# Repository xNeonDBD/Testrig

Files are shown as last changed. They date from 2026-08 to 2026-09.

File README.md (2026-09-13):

# Line Following Robot

A compact line-following robot designed around an ESP32, N20 geared motors with encoders, and a straight analog IR sensor array.

The chassis went through **three main design stages** — V1, V2, and V2 Final — before settling on a simpler, more practical, and more printable layout. This README documents each stage in order, including what changed and why.

---

## Components

### Electronic

- **Microcontroller:** ESP32
  - Specific version: __________
- **IR Sensor Array:** Analog straight IR sensor array
- **Motor Driver:** TB6612FNG
- **Battery:** 2 × 2.7 V Li-ion batteries
- **Battery Holder:** 1
- **Power Converter / Buck Converter:** __________

### Mechanical

- **Motors:** 2 × N20 6 V geared motors with encoders
- **Wheels:** 2 × high-traction 32 mm wheels
- **Caster Wheel:** 1 × caster ball mount
- **Chassis:** Custom CAD-designed chassis
- **Fasteners:** M2.0 nuts and screws

---

## Chassis Design History

### V1 — Curved IR Array Design (Dropped Early)

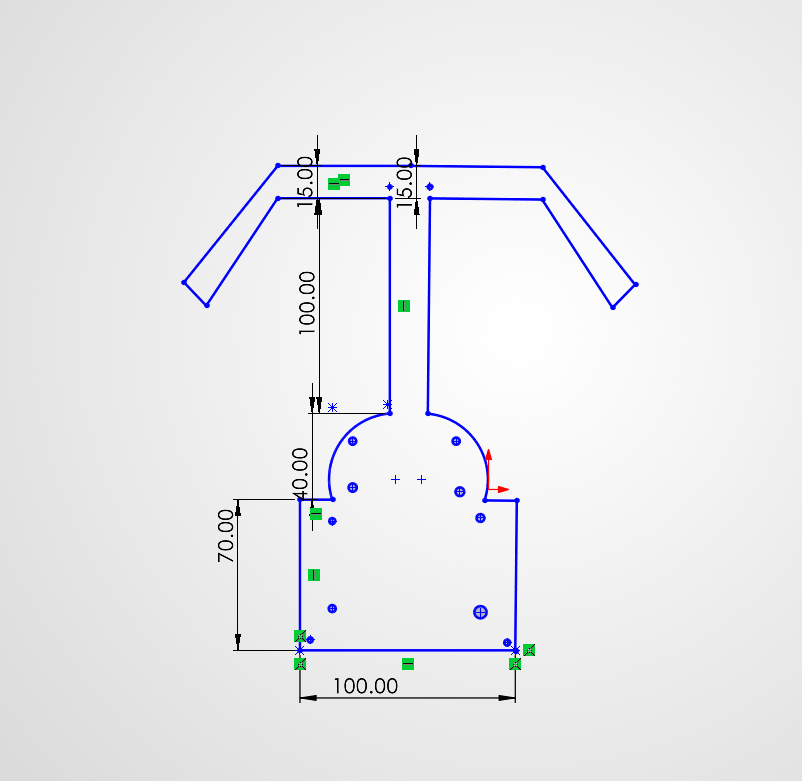
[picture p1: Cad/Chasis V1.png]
Chassis V1


The first version was designed around a **curved IR sensor array**. The idea was to place the sensors along a curved front section so the array could cover a wider area while following the line. The chassis also had to accommodate the required sensor mounting holes and spacing.

This version was **abandoned very quickly**, before it went far into detailed CAD, once two major problems became clear:

1. **Coding complexity** — A curved sensor arrangement requires more complicated sensor mapping and calibration. Since the sensor positions aren't evenly aligned along a straight line, converting the readings into a reliable position/error value is more difficult.
2. **CAD hole spacing** — Getting the correct hole positions, lengths, and widths for the curved arrangement became a problem almost immediately during modelling. Small changes in sensor dimensions or mounting positions affected the rest of the chassis.

Rather than pushing through these issues, the curved-array design was dropped early in favour of a simpler straight sensor arrangement, which became V2.

---

### V2 — Straight Array with Diagonal Slots

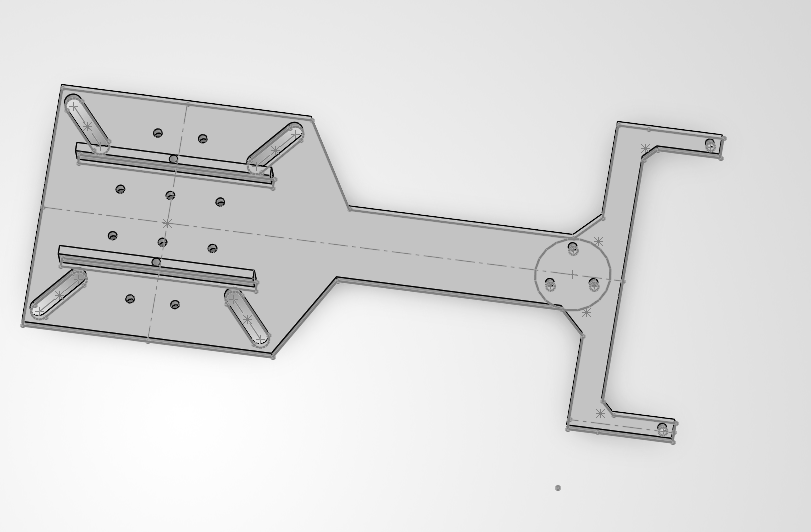
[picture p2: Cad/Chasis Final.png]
Chassis V2


V2 replaced the curved array with a **straight analog IR sensor array**, since sensors on a single straight line are far easier to read, calibrate, and map to a position/error value.

**Key changes from V1:**

- Replaced the curved IR array with a straight analog IR array.
- Added a **long straight mounting slot** for the IR sensor/PCB, so sensor position could be adjusted instead of fixed.
- Improved the PCB mounting arrangement.
- Added two large rectangular recessed/extruded sections for the battery holder, so it sits securely instead of shifting during operation.
- Battery holder/PCB could be secured further with mounting screws if needed.

**Why diagonal slots were used for mounting holes:**

At this stage, most of the mounting holes (not just the IR sensor mount) were also cut as **diagonal/angled slots** rather than fixed circular holes. The reasoning at the time was to build in extra tolerance — since the chassis depends on several separate components (motors, PCB, battery holder) lining up together, slots gave room to shift each part slightly during assembly to compensate for small CAD or print inaccuracies, without needing to redesign or reprint the chassis. It felt like a safer, more forgiving choice while the exact component dimensions were still being finalised.

This made V2 more flexible during initial assembly, but it introduced a new problem that only became clear once parts were actually mounted and tested — covered in V2 Final below.

---

### V2 Final — Fixed Holes + Reduced Width

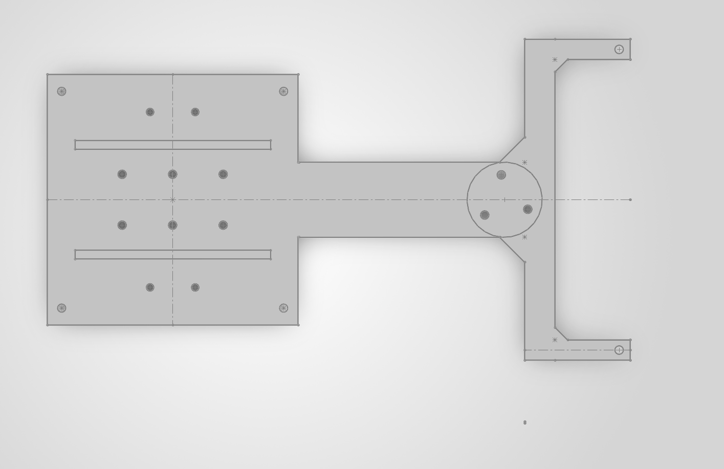
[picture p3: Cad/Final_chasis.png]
Chassis Final


V2 Final keeps the straight IR array and general layout from V2, but corrects two problems discovered after building and testing V2: loose mounting and a chassis that didn't fit the printer.

**Change 1 — All slots removed, replaced with fixed holes:**

Every slot used for mounting in V2 — including the IR sensor mounting slot — was **removed and replaced with fixed-position circular holes** at defined spacing. The chassis no longer has any adjustable mountings.

The extra tolerance from slots turned out to cause more problems than it solved: mounting screws sat loose inside the slots instead of clamping tightly, letting the PCB, sensor array, and brackets shift slightly under vibration or load from the motors. Fixed holes with accurate, pre-calculated spacing removed that play entirely, giving a tighter, more repeatable, more rigid assembly across every mounting point on the chassis.

**Change 2 — Overall chassis width reduced:**

The original V2 chassis was too **long to fit flat on the 3D printer's build plate**. The only way to print it at that size would have been to stand it up at an angle and rely on support structures, which was rejected for three reasons:

1. **Resource waste** — angled printing with supports uses a large amount of extra filament that just gets discarded afterward.
2. **Holes get blocked by supports** — mounting and sensor holes risked being filled in or distorted by support material generated underneath them, requiring cleanup and risking inaccurate final dimensions.
3. **Excessive print time** — for a relatively simple, flat chassis part, printing vertically with supports takes far longer than justified.

To avoid all three issues at once, the chassis **width was reduced** so the entire part fits flat on the print bed in a single orientation, with no supports required.

**Net result:** V2 Final is fully rigid (no loose slots anywhere), lighter, simpler to assemble, and cheaper/faster to print (flat, no supports) than V2 — without losing any of the functional improvements V2 made over V1.

---

## Chassis Design Features

### Lightweight, Simple Chassis

V2 Final favours a **lightweight and simple structure** over the more complex, feature-heavy layout of earlier revisions. With slots removed in favour of fixed holes and the width trimmed down to fit the print bed, the chassis uses less material, prints faster, and has fewer geometric features that could go wrong during modelling or printing. The design prioritises a clean, repeatable, no-frills structure that's easy to assemble and easy to reprint if needed.

```text
        IR SENSOR ARRAY
    ─────────────────────
              ↑
          Fixed hole
    ─────────────────────

             CHASSIS
```

### Fixed Mounting Holes (V2 Final)

All mounting holes on the chassis — including the IR sensor mount, PCB/electronics mounting, and the motor-side mounting pattern — use **fixed circular holes** at defined spacing, visible in `Final_chasis.png`. There are no adjustable/slotted mountings left on the current chassis.

Fixed holes were chosen over slots because:

- Slots allowed the mounting screws to sit loose rather than clamping tightly.
- Loose screws risk shifting the PCB, sensor, or bracket position over time, especially with vibration from the motors.
- Fixed holes with accurate spacing give a more rigid, repeatable assembly once tightened.

### Reduced Chassis Width (V2 Final)

The V2 chassis length exceeded the 3D printer's flat build area. Printing it as-is would have required standing the part up at an angle with support structures, which was rejected for three reasons:

- **Wasted material** — supports consume significant extra filament for no functional benefit.
- **Blocked holes** — mounting and sensor holes could get filled or distorted by support material underneath them.
- **Long print time** — a simple flat chassis shouldn't need a lengthy angled/supported print.

The chassis width was reduced in V2 Final so the whole part prints flat on the bed in one orientation, with no supports needed.

### Battery Mount

Two large rectangular sections provide a stable location for the battery holder. It can be placed on top of the base and secured with mounting screws if required, preventing the batteries from shifting during sharp turns.

### Caster Ball Mount

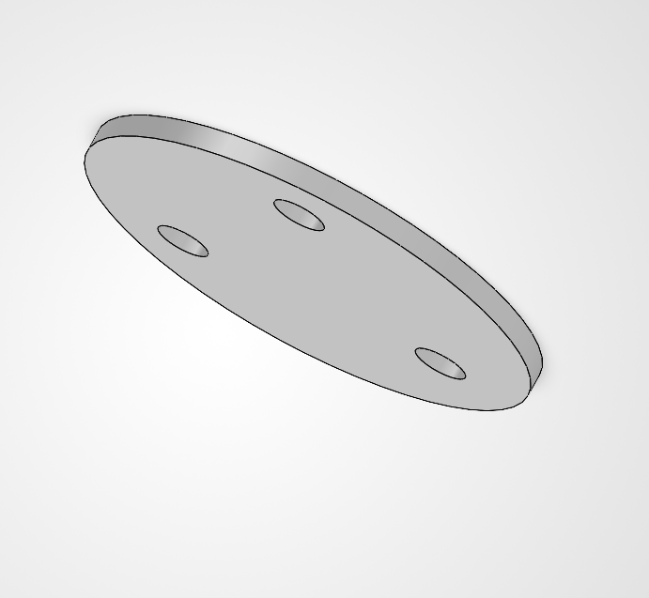
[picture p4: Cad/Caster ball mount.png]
Caster Ball Mount


The caster ball mount (`Caster_Ball_Mount.SLDPRT`) is currently a **working/scratch file**, kept separate from the main chassis so it can be freely edited and iterated on.

It's being used to test and lock down:

- Motor mounting hole positions and spacing for the 2 N20 motors
- Final caster ball mounting height and hole dimensions relative to the wheels

Once the correct dimensions are confirmed through physical testing, the finalised values will be transferred into the main chassis file (`Chasis_final.SLDPRT`).

### Bracket

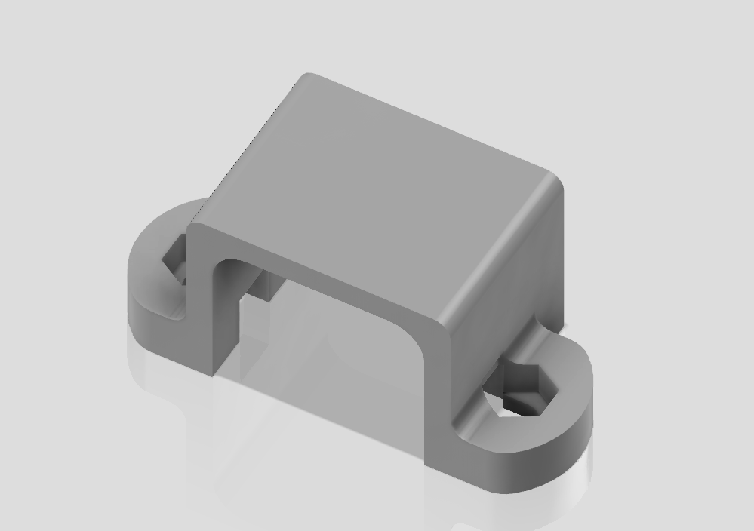
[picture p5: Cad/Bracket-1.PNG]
Bracket


A supporting bracket part (`Bracket.SLDPRT`) used alongside the chassis assembly.

---

## CAD Design

The chassis was designed with emphasis on:

- Simple manufacturability
- Lightweight, low-material structure
- Easy PCB mounting
- Secure battery placement
- Easy access to electronics
- Compatibility with N20 motors and 32 mm wheels
- Fitting flat on the 3D printer bed without supports

Final chassis dimensions and hole positions may still be adjusted after physical testing, since actual component tolerances can differ from CAD dimensions.

### CAD Change Log (Chronological)

| Stage | Change | Reason |
|---|---|---|
| V1 → V2 | Curved IR array replaced with straight IR array | Curved layout caused sensor-mapping/coding complexity and CAD hole-spacing problems |
| V2 | Diagonal/angled slots used for general mounting holes | Intended to give tolerance for component/print inaccuracies during assembly |
| V2 → V2 Final | All slots removed, including the IR sensor slot, replaced with fixed circular holes at defined spacing | Slots left mounting screws too loose, allowing parts to shift under vibration or load; chassis no longer needs adjustable mounts |
| V2 → V2 Final | Overall chassis width reduced | Original V2 length didn't fit flat on the print bed; avoids wasteful angled/supported prints |

---

## Assembly

1. Mount the two N20 motors to the chassis.
2. Install the 32 mm wheels on the motor shafts.
3. Install the caster ball mount.
4. Mount the ESP32 and motor driver.
5. Install the analog IR sensor array.
6. Place the two Li-ion batteries in the battery holder.
7. Secure the battery holder using the provided mounting arrangement.
8. Connect the motors, encoder outputs, IR array, ESP32, motor driver, and power system.
9. Confirm all fixed mounting holes are properly tightened.

---

## Design Considerations

One of the main problems throughout the CAD stage was **hole placement and dimensional accuracy**. Since the chassis depends on several different components being mounted together, even a small error in hole spacing or width can cause problems during physical assembly.

V1 was dropped almost immediately because a curved sensor layout compounded both coding complexity and CAD hole-spacing issues, so effort was redirected into a straight-array design (V2) very early.

V2 initially used diagonal slots liberally across the mounting holes, treating adjustability as a safety margin against CAD or print inaccuracy. In practice, this backfired — slots meant to smooth over minor errors and screws sat loose instead of clamping, letting parts shift under vibration. V2 Final corrected this by converting every mounting hole, including the IR sensor mount, to fixed positions with accurate spacing. The chassis is now built entirely around fixed, rigid mounting rather than adjustability.

Manufacturability on the actual printer also forced a change in V2 Final. The original V2 length couldn't fit flat within the print bed, and printing it angled with supports would have wasted filament, risked blocking holes with support material, and taken far longer than justified for a simple flat part. Reducing the chassis width solved all three problems at once by keeping the whole print flat and support-free, while also keeping the design lightweight and simple.

---

## Testing Checklist

- Motor mounting hole alignment
- Wheel clearance
- Caster height
- IR sensor height from the track
- IR sensor position relative to the wheels
- Battery holder fit
- PCB mounting holes
- Screw clearance
- Cable routing
- Overall chassis balance
- Fixed mounting holes are tight with no play (post slot-removal)
- Chassis prints flat on the bed without supports

---

## Future Improvements

- Finalising the exact ESP32 variant
- Improving PCB mounting
- Final circuit design
- Maze solving algorithm
- Adding IMU for perfect turning
- Testing different types of IR sensors (digital vs analog)
- Optimising the chassis after the first physical prototype

---

## Repository Structure

```text
.
├── Cad/
│   ├── Bracket-1.PNG
│   ├── Bracket.SLDPRT
│   ├── Caster ball mount.png
│   ├── Caster_Ball_Mount.SLDPRT
│   ├── Chasis Final.png
│   ├── Chasis V1.png
│   ├── Chasis.SLDPRT
│   ├── Chasis_final.SLDPRT
│   └── Final_chasis.png
├── Docs/
│   └── Components/
├── Firmware/
├── BUILDLOG.md
└── README.md
```

---

## Current Status

| Part | Status |
|---|---|
| N20 6 V Motors | Selected |
| ESP32 | Selected — version TBD |
| Motor Driver | TB6612FNG |
| IR Sensor | Straight analog array |
| Battery | 2 × Li-ion |
| Battery Holder | Selected |
| Wheels | Selected |
| Chassis V1 | Dropped early (curved array issues) |
| Chassis V2 | Superseded (diagonal slots caused loose mounting) |
| Chassis V2 Final | Current design (`Chasis_final.SLDPRT` / `Final_chasis.png`) |
| PCB Mounting | Fixed holes (all slots removed in V2 Final) |
| Chassis Width | Reduced in V2 Final to fit print bed flat |
| IR Sensor Mount | Fixed hole (no longer adjustable) |
| Battery Mount | Added |
| Caster Ball Mount | In progress — scratch file for dimension testing |

---

## Notes

This chassis is still a prototype. Final dimensions may change after testing the actual motors, wheels, sensor array, battery holder, and electronics together.

**V1** was only a brief exploration — dropped very quickly once the curved sensor array introduced compounding coding and CAD problems.

**V2** introduced the straight sensor array and used slots across most mounting points to allow for assembly tolerance — a choice that later proved to make the assembly too loose.

**V2 Final** fixed both remaining issues from V2: every mounting hole, including the IR sensor mount, was converted to a fixed, precisely spaced hole for rigidity, and the chassis width was reduced so the part prints flat on the bed without wasteful, hole-blocking, time-consuming angled supports. The chassis is now lightweight, simple, and fully fixed — no adjustable mountings remain.

The main goal of the current (V2 Final) design is to keep the robot simple, lightweight, rigid, and easy to manufacture on the available 3D printer.
</content>

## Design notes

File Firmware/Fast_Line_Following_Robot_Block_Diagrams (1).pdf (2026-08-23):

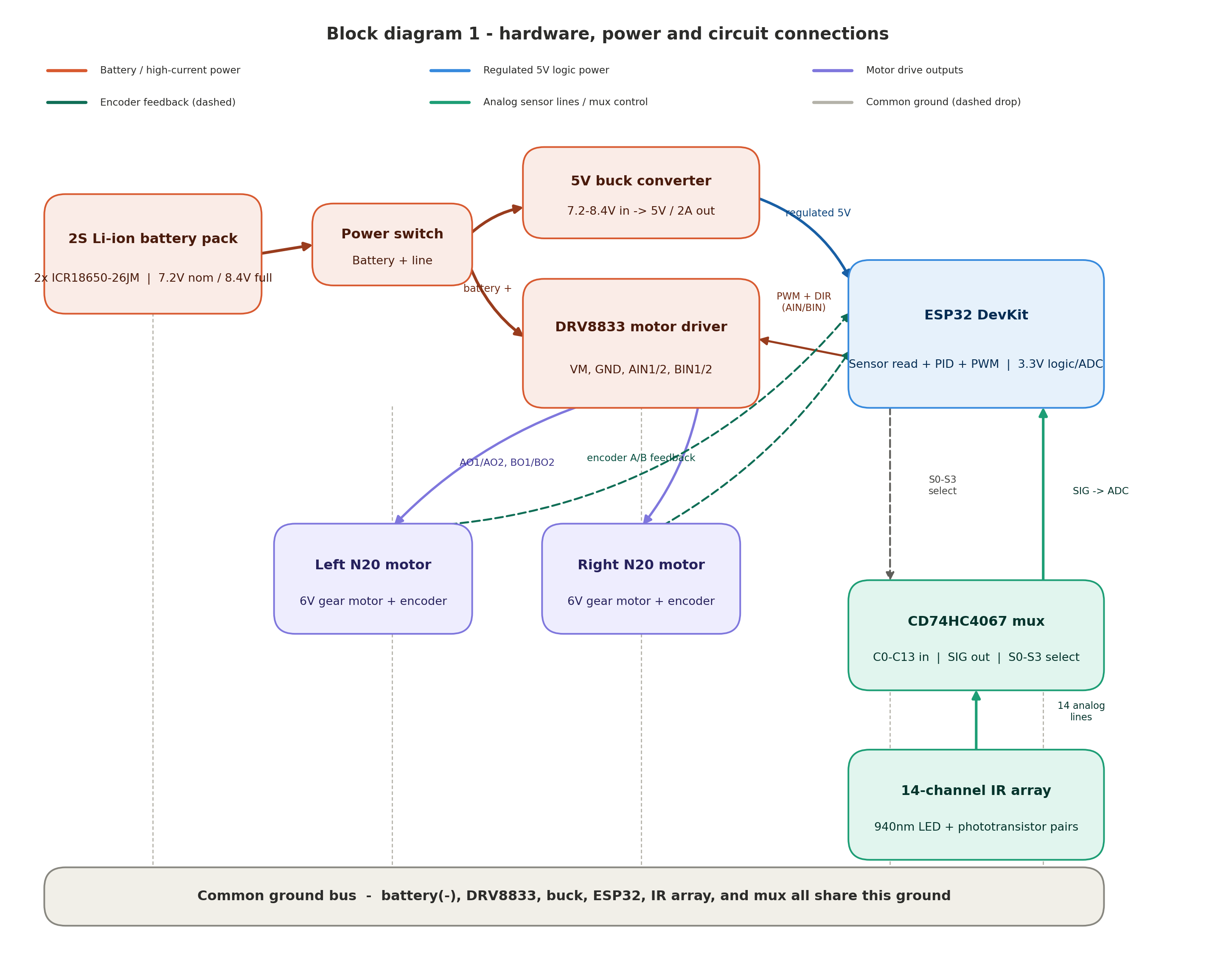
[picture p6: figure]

Fast line-following robot - block diagrams | page 1

# Fast line-following robot

Final block diagrams | ESP32 · DRV8833 · 2x N20 encoder motors · 14-channel analog IR array ·

### CD74HC4067 multiplexer

## 1. Hardware, power and circuit connections

Power flows from the 2S Li-ion pack through the main switch to two regulators: the DRV8833 takes raw battery voltage for the motors, and the buck converter steps it down to a regulated 5V rail for the ESP32 and sensor electronics. The ESP32 closes the loop by reading the IR array through the multiplexer and driving the motors through the DRV8833, using encoder feedback to track wheel speed. Every module shares one common ground.

### Critical wiring notes

- The battery's 8.4V never connects to the ESP32 directly - only the DRV8833 motor supply (VM) sees raw battery voltage.
- The ESP32 is powered exclusively from the regulated 5V buck converter output (5V / VIN pin).
- All six grounds - battery negative, DRV8833, buck converter, ESP32, IR array, and multiplexer - must tie to one common ground.
- DRV8833 STBY must be held HIGH (tie to 3.3V or an ESP32 GPIO driven HIGH), or the motor outputs stay disabled.
- Add a 470-1000 uF electrolytic capacitor across DRV8833 VM-GND, close to the driver, plus 100 nF ceramic capacitors near the ESP32 and multiplexer supply pins to suppress motor-switching noise.

## 2. Two-level control loop

The firmware runs two nested PID loops. The outer loop reads all 14 IR sensors once per scan, computes a weighted line position, and turns the resulting error into a steering correction and a pair of target wheel speeds. The inner loop runs once per wheel: it compares the target RPM against the actual RPM measured by the quadrature encoder and adjusts PWM duty cycle to close the gap.

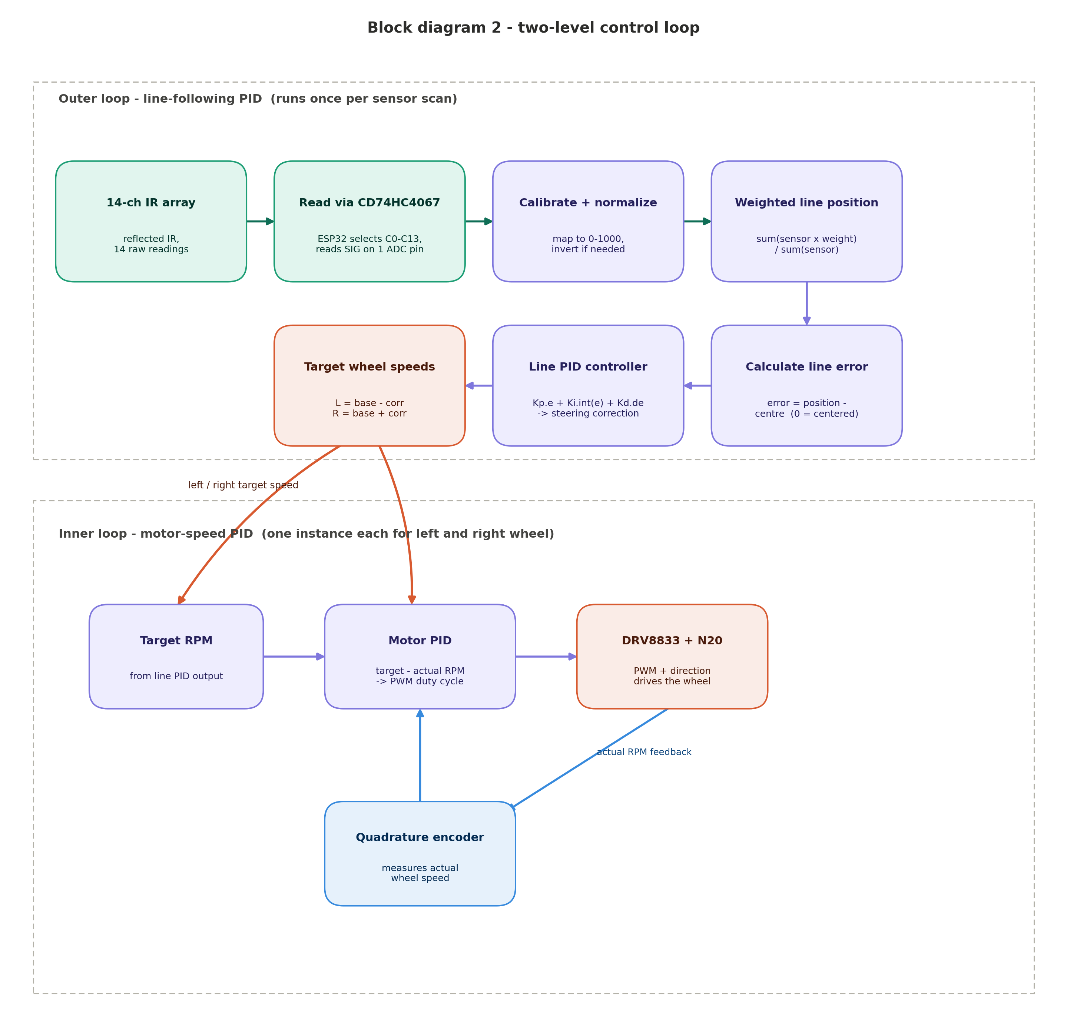
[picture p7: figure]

### How steering happens

- Line left of center → correction is negative → left target speed decreases, right target speed increases → robot turns left.
- Line right of center → correction is positive → left target speed increases, right target speed decreases → robot turns right.
- For sharp turns the firmware may reverse one motor - no mechanical differential or steering servo is required.

## 3. Final component reference

This table matches the two diagrams above. Items marked “optional” strengthen a physical build (power filtering, fusing) but can be omitted only for idealized simulation.

Subsystem | Component / circuit | Qty | Key specification / connection
Controller | ESP32 DevKit | 1 | ESP32-WROOM-32; 3.3V GPIO/ADC; powered from regulated 5V VIN/5V pin
Sensors | 940 nm IR LED | 14 | One per sensing position, each with a 220 Ω series resistor
Sensors | Phototransistor | 14 | One per IR LED, each with a 10 kΩ load/pull-down resistor; analog output
Sensors | CD74HC4067 | 1 | 16:1 analog multiplexer; C0-C13 from sensors, SIG to ESP32 ADC, S0-S3 from ESP32
Motors | N20 DC gear motor + quadrature encoder | 2 | 6V class; left and right wheels driven independently
Motor driver | DRV8833 breakout board | 1 | VM from battery; AIN1/2, BIN1/2 from ESP32; STBY held HIGH; AO/BO to motors
Battery | Samsung ICR18650-26JM | 2 | Identical cells in series (2S): 7.2V nominal, 8.4V full
Battery safety | 2S BMS + 8.4V Li-ion charger | 1 each | BMS rated at least 8-10 A; charger designed for 2S Li-ion
Power | 5V buck converter | 1 | Input 7.2-8.4V; output 5V; rated ≥ 2A for ESP32 and sensor electronics
Power | Switch, fuse, wiring, pack holder | 1 set | Switch in battery positive line; optional 3A fuse; common ground everywhere
Filtering (optional) | 470-1000 uF electrolytic capacitor | 1 | Across DRV8833 VM and GND, close to the driver
Filtering (optional) | 100 nF ceramic capacitor | 2-3 | Near ESP32, multiplexer, and/or driver supply pins
Mechanics | Wheels + low-friction front skid | 2 + 1 | 30-40 mm wheels; skid or caster provides the third contact point

### Critical wiring notes

- Do not connect the 8.4V battery rail directly to the ESP32.
- The DRV8833 motor supply (VM) receives raw battery voltage; the ESP32 receives regulated 5V from the buck converter.
- All grounds must be tied together on one common bus.
- DRV8833 STBY must be driven HIGH (3.3V or an ESP32 GPIO set HIGH), or the motor outputs remain disabled.

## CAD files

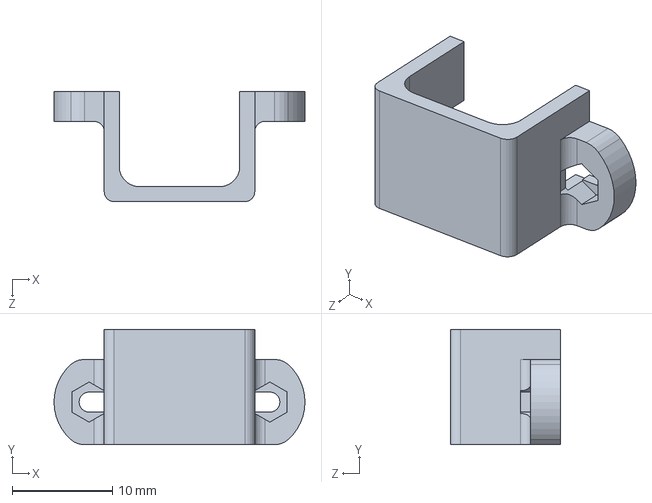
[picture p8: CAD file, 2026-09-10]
Cad/Bracket.SLDPRT
25.0 x 11.5 x 11.0 mm

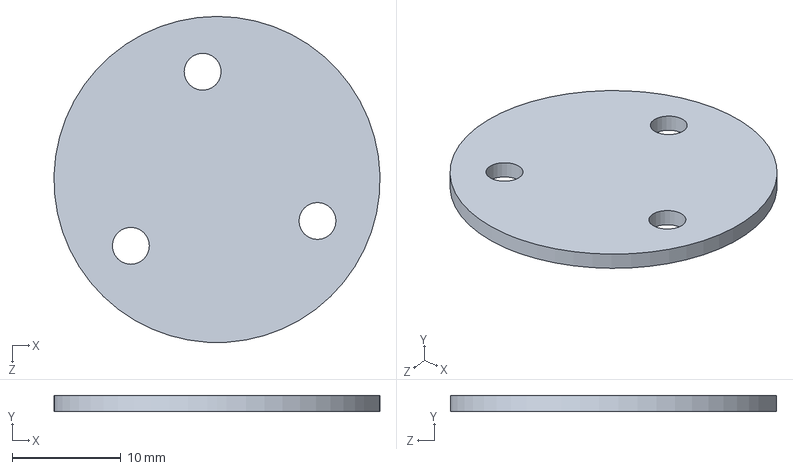
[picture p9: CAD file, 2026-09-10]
Cad/Caster_Ball_Mount.SLDPRT
30.0 x 1.50 x 30.0 mm

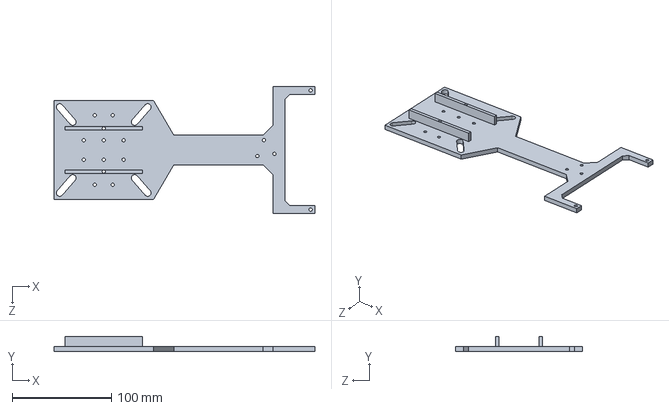
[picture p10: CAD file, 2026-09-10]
Cad/Chasis_final.SLDPRT
262.5 x 15.0 x 128.1 mm

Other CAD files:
Cad/Chasis.SLDPRT

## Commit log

2026-08-16 Folders creation
    First time using github. Created format as requested by current RMI saiprakash ana
2026-08-16 Delete Firmware./cad directory
    Delete mistake
2026-08-23 Chasis v1
    Make sure to redo the chasis properly this is a hastily made base
    [Chasis.SLDPRT]
2026-09-10 Made final version of chasis
    i need to fifure out the lenght and diameter of motor mounting holes onto chasis only that is left
    [Bracket.SLDPRT, Caster_Ball_Mount.SLDPRT, Chasis_final.SLDPRT]
2026-09-10 Revise README for chassis design updates
    Updated README to clarify the status of V1 and its issues, added details about the supporting bracket, and improved descriptions of CAD design challenges.
2026-09-10 Update sensor mount terminology and fix typo
    Updated references from 'IR sensor array' to 'PCB/perfboard' and corrected a typo in the description of the caster ball mount.
2026-09-13 final version i have 3d printed
2026-09-13 Revise component details and chassis design features
    Updated specifications for components and design features in the README. Improved clarity on the chassis design changes and assembly considerations.
2026-09-13 Revise README for chassis design history and updates
    Updated the README to reflect the design history and changes of the chassis for the line-following robot, including detailed descriptions of the V1, V2, and V2 Final stages.
2026-09-13 Revise hardware specifications and future improvements
    Updated motor driver and battery holder specifications, and added future improvement items.
2026-09-13 Update README with changes to IR sensor mounting
    Removed the adjustable slot for the analog IR sensor array and updated related assembly instructions. Clarified the design changes from V2 to V2 Final regarding mounting hole adjustments.
